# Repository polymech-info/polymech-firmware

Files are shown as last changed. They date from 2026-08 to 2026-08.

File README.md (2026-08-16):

# Polymech FW Apps

Monorepo for the Polymech Cassandra control system — ESP32-S3 firmware, web interface, maintenance tooling, and supporting libraries.

> **WIP / Roadmap**
> - Adopt new widget system for the web interface
> - Migrate firmware build to ESP-IDF native (drop PlatformIO)

## Overview

The firmware is a general-purpose embedded control platform for industrial recycling and forming machinery. **Cassandra** is the reference application built on top of it — not the framework itself. Any application is composed by enabling features in `config.h` and dropping local overrides into `config-user.h`, with no changes required to the core codebase.

**Composable components** (toggled via `#define`):

- **VFDs** — Sako, Delta, HY (RS-485 Modbus RTU)
- **Temperature control** — Omron E5 series PID controllers (up to N devices, configurable slave IDs)
- **Pressure / force** — load cells, press cylinders, solenoids
- **Motion** — stepper axes, joystick, operator switches
- **Profiles** — temperature warm-up sequences, pressure profiles, signal plots
- **Connectivity** — Modbus TCP, RS-485, REST API, WebSocket, LittleFS web UI
- **Budgeting** — amperage budget manager for shared power rails

The web interface (`modbus-ui`) is equally composable: pages and widgets map to the Modbus/REST surface exposed by whatever components are enabled in firmware.

**Supported machine types:** injection moulders, sheet presses, shredders, extruders, vending machines, and any custom application that combines VFDs, PID zones, and relay/solenoid outputs.

> **Status:** Battle-tested over many months of continuous operation on real production hardware.

## Repository Layout

| Path | Description |
|---|---|
| [`cassandra-rc2/`](./cassandra-rc2/README.md) | Main firmware (PlatformIO / ESP32-S3). Exposes Serial, Modbus TCP, and a REST/Web UI. |
| [`web/packages/modbus-ui/`](./web/packages/modbus-ui/) | React operator interface for the device, served over WiFi. |
| [`web/packages/client/`](./web/packages/client/) | Shared TypeScript client library used by the web packages. |
| [`cli-ts/`](./cli-ts/) | Node.js / TypeScript maintenance CLI — configuration management, network setup, signal plotting, and device scripting. |
| [`mb-script/`](./mb-script/) | Scriptable Modbus sequencer firmware for automated register-level testing and commissioning. |
| [`playground/`](./playground/) | Isolated PlatformIO sandbox for prototyping firmware features before merging into the main build. |
| [`tools/`](./tools/) | Pre-built Windows binaries and upload scripts (`esptool`, `espflash`, Modbus Poll/Slave, flash download tool, `zadig`, etc.). |
| [`vendor/`](./vendor/) | Third-party datasheets and reference material (Delta, Omron, Waveshare, HY, Kincony, and others). |

## Requirements

### Firmware (`cassandra-rc2/`)

The firmware supports two build backends. **ESP-IDF native** is the target going forward; PlatformIO remains available for the existing Waveshare/ESP32-S3 targets.

| Requirement | Notes |
|---|---|
| **PlatformIO Core** (`pio`) | `pip install platformio`. Used for `waveshare` / `waveshare-release` / `esp32-p4-evboard` environments. |
| **ESP-IDF v5.3.1** | Install via the [Espressif installer](https://docs.espressif.com/projects/esp-idf/en/stable/esp32s3/get-started/). Path assumed at `C:\Espressif\frameworks\esp-idf-v5.3.1`. Used by `idf:build` / `idf:flash` / `idf:monitor` scripts (via `scripts/idf-*.sh`). |
| **CMake ≥ 3.24** | Bundled with ESP-IDF; ensure it is on `PATH` for native IDF builds. |
| **Python ≥ 3.10** | Required by PlatformIO, `esptool`, Modbus test scripts, and the nanopb generator (`scripts/run_nanopb_generator.py`). Run `npm run idf:setup` to install the IDF Python venv. |
| **Node.js ≥ 20 + npm** | Drives all `npm run …` wrapper scripts. |
| **VSCode** | Recommended editor. Install either: |
| &nbsp;&nbsp;↳ **ms-vscode.cpptools** | Microsoft C/C++ extension — works out of the box with the PlatformIO-generated `compile_commands.json` (`npm run index`). |
| &nbsp;&nbsp;↳ **llvm-vs-code-extensions.vscode-clangd** | clangd — faster indexing; requires the same `compile_commands.json` and disabling ms-cpptools IntelliSense. |
| **Bash** | Required for `idf:*` and `web:*` shell scripts. On Windows use Git Bash or WSL. |

### Web interface (`web/packages/modbus-ui/`)

| Requirement | Notes |
|---|---|
| **Node.js ≥ 20 + npm** | `npm install` in `web/packages/modbus-ui/` and `web/packages/client/`. |

### Maintenance CLI (`cli-ts/`)

| Requirement | Notes |
|---|---|
| **Node.js ≥ 20 + npm** | `npm install` in `cli-ts/`. |

## References

- [OSR - Plastic Legacy Firmware (Shredders, Printhead)](https://git.polymech.info/osr-plastic/osr-firmware.git)
- [Cassandra 65cm — PolyMech Service](https://service.polymech.info/user/3bb4cfbf-318b-44d3-a9d3-35680e738421/pages/cassandra-65cm)
- [Elena - Injection Machine (Motorized) — PolyMech Service](https://service.polymech.info/user/3bb4cfbf-318b-44d3-a9d3-35680e738421/pages/elena-injection-machine-motorized)

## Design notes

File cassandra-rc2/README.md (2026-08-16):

# Polymech Cassandra Firmware

This repository contains the firmware for the Polymech Cassandra project, running on an ESP32-S3.

## Overview

The firmware manages various hardware components and provides multiple interfaces for control and monitoring:

* **Serial Interface:** For debugging, testing, and direct command execution.
* **Modbus TCP Server:** Allows interaction with components using the Modbus protocol over WiFi.
* **REST API & Web UI:** Provides a web-based interface (status page, API documentation) and a RESTful API for interacting with the system over WiFi.

## Architecture

The firmware is built upon a component-based architecture:

* **`App` / `PHApp`:** The main application class (`src/PHApp.h`).
* **`Component`:** Base class (`src/Component.h`) for all functional units.
* **`Bridge`:** (`src/Bridge.h`) Facilitates serial command dispatch.
* **`SerialMessage`:** (`src/SerialMessage.h`) Handles serial communication.
* **`ModbusManager`:** (`src/ModbusManager.h`) Manages the Modbus TCP server.
* **`RESTServer`:** (`src/RestServer.h`) Implements the web server and REST API.
* **Details:** See [docs/components.md](./docs/components.md) for how components are structured, configured, and added.

## Interfaces

### 1. Serial Communication

A command-line interface is available over the USB serial port used for programming and monitoring.

* **Purpose:** Debugging, direct method calls on components.
* **Command Format:** `<<component_id;call_type;flags;payload:arg1:arg2...>>`
* **Examples & Details:** See [docs/serial.md](./docs/serial.md)
* **Sending Commands:** Use `npm run send -- "<command_string>"` or a standard serial terminal.

### 2. Modbus TCP

The device runs a Modbus TCP server (slave/responder) on port 502.

* **Implementation:** Managed by `ModbusManager` using the `eModbus` library.
* **Component Interaction:** Components supporting Modbus (like `Relay` or `PHApp` itself) implement `readNetworkValue` and `writeNetworkValue` methods. They are registered with the `ModbusManager` along with their corresponding Modbus addresses.
* **Configuration:** Modbus addresses are defined in `src/config-modbus.h`.
* **Design Details:** See [docs/design-network.md](./docs/design-network.md)
* **Testing:** Use the `python scripts/modbus_*.py` scripts directly (npm script argument passing has issues):

    ```bash
    # Read Coil 51
    python scripts/modbus_read_coils.py --address 51 --ip-address <DEVICE_IP>
    # Write Coil 51 ON
    python scripts/modbus_write_coil.py --address 51 --value 1 --ip-address <DEVICE_IP>
    # Read Register 20
    python scripts/modbus_read_registers.py --address 20 --ip-address <DEVICE_IP>
    # Write Register 20
    python scripts/modbus_write_register.py --address 20 --value 123 --ip-address <DEVICE_IP>
    ```

### 3. Web Interface & REST API

A web server runs on port 80, providing:

* **Status Page:** `http://<DEVICE_IP>/`
* **Swagger UI:** `http://<DEVICE_IP>/api-docs` (Interactive API documentation)
* **REST API:** `http://<DEVICE_IP>/api/v1/...`
* **Working Endpoints:**
  * `GET /api/v1/system/info`: Device status.
  * `GET /api/v1/coils`: List of registered coils.
  * `GET /api/v1/registers`: List of registered registers.
  * `GET /api/v1/coils?address=<addr>`: Read a specific registered coil.
  * `GET /api/v1/registers?address=<addr>`: Read a specific registered register.
  * `POST /api/v1/relay/test`: Trigger internal relay test.
* **Non-Functional Endpoints (Known Issue):**
  * `POST /coils/{address}`: Returns 404.
  * `POST /registers/{address}`: Returns 404.
* **Details & Examples:** See [docs/web.md](./docs/web.md)
* **Testing:** Use `npm run test-api-ip` (note that some tests related to POST endpoints will fail).

## Building and Development

See [firmware/.cursor/rules](./.cursor/rules) for a summary of common workflow commands.

**Key `npm` Scripts:**

* `npm run build`: Compile the firmware.
* `npm run upload`: Upload the firmware to the device.
* `npm run clean`: Clean build artifacts.
* `npm run monitor`: Open the serial monitor.
* `npm run build-web`: Generate web assets (from `swagger.yaml`, `front/`) and build firmware.
* `npm run send -- "<command>"`: Send a serial command.
* `npm run test-api-ip`: Run the REST API test script against the device IP.
* *(Modbus tests need direct python execution, see Modbus section above)*

## Configuration

* **Hardware Pins, Features:** `src/config.h`, `src/config_adv.h`
* **WiFi Credentials:** `src/config_secrets.h` (ensure this file exists and is populated)
* **Modbus Addresses:** `src/config-modbus.h`
* **Component IDs:** `src/enums.h` (enum `COMPONENT_KEY`)

## Todos

### Web

* [x] pid stats
* [ ] prof enabled
* [ ] warmup toggle
* [-] press prof - remaining ( parent )
* [ ] auto - interlock ( rs 485 connect ) => modes
* [ ] press : sp ( ui - mobile)
* [ ] partitions : settings not applied

### FW

* [x] press - profile ( check abort => vis error )
* [x] sp drag / lag

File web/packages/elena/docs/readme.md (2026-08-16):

# Cassandra RC2 Temperature Control System

The Cassandra RC2 is a temperature control system designed for precise thermal management across multiple heat zones. This web interface allows operators to monitor and control various heating elements arranged in zones with support for temperature profiles.

## System Architecture

The following diagram shows the high-level architecture of the Cassandra RC2 system:

```mermaid
flowchart TD
    UI[Web Interface] --> API[API Client]
    API --> CS[Controller Service]
    API --> PS[Profile Service]
    API --> ZS[Zone Service]
    CS --> SS[Storage Service]
    PS --> SS
    ZS --> SS
    SS --> DB[Supabase Database]
```

## Data Model

The core data entities in the system are:

```mermaid
erDiagram
    HeatZone ||--o{ Controller : contains
    Controller }|--o| TemperatureProfile : runs
    TemperatureProfile ||--|{ ControlPoint : contains

    HeatZone {
        string id
        string name
        string description
    }

    Controller {
        string id
        string name
        number currentTemp
        number targetTemp
        number minTemp
        number maxTemp
        number slaveId
        number updateInterval
        string currentProfile
        boolean isRunning
        string lastUpdated
        string zoneId
    }

    TemperatureProfile {
        string id
        string name
        string description
        array controlPoints
        number duration
        string createdAt
        string updatedAt
    }

    ControlPoint {
        number x
        number y
        number handleX
        number handleY
        string type
    }
```

## Component Hierarchy

The React component hierarchy for the main interface:

```mermaid
flowchart TD
    Index[Index Page] --> MainNav[Main Navigation]
    Index --> ZoneCard[Zone Cards]
    ZoneCard --> ZMC[Zone Master Control]
    ZoneCard --> TC[Temperature Controllers]
    Index --> Dialogs[Dialog Components]
    Dialogs --> PD[Profile Dialog]
    Dialogs --> ACD[Add Controller Dialog]
    Dialogs --> ECD[Edit Controller Dialog]
    Dialogs --> AZD[Add Zone Dialog]

    TC --> Info[Controller Info]
    TC --> TempDisplay[Temperature Display]
    TC --> Controls[Control Buttons]

    ZMC --> Visualization[Heat Press Visualization]
    ZMC --> ZoneControls[Zone-wide Controls]
    ZMC --> ProfileProgress[Profile Progress]
```

## API Structure

The API client provides these main function groups:

```mermaid
flowchart LR
    API[API Client] --> ZoneFunctions[Zone Functions]
    API --> ProfileFunctions[Profile Functions]
    API --> ControllerFunctions[Controller Functions]

    ZoneFunctions --> getZones[getZones]
    ZoneFunctions --> getZone[getZone]
    ZoneFunctions --> createZone[createZone]
    ZoneFunctions --> deleteZone[deleteZone]
    
    ProfileFunctions --> getProfiles[getProfiles]
    ProfileFunctions --> getProfile[getProfile]
    ProfileFunctions --> createProfile[createProfile]
    ProfileFunctions --> updateProfile[updateProfile]
    ProfileFunctions --> deleteProfile[deleteProfile]
    
    ControllerFunctions --> getControllers[getControllers]
    ControllerFunctions --> getController[getController]
    ControllerFunctions --> updateController[updateController]
    ControllerFunctions --> startController[startController]
    ControllerFunctions --> stopController[stopController]
    ControllerFunctions --> createController[createController]
    ControllerFunctions --> deleteController[deleteController]
```

## Temperature Control Flow

The temperature control system functions as follows:

```mermaid
sequenceDiagram
    actor User
    participant UI as Web Interface
    participant API as API Client
    participant Storage as Storage Service
    
    User->>UI: Set target temperature
    UI->>API: updateController(id, {targetTemp})
    API->>Storage: Save updated controller
    Storage-->>API: Confirmation
    API-->>UI: Updated controller object
    UI-->>User: Display updated temperature
    
    User->>UI: Apply temperature profile
    UI->>API: startController(id, profileId)
    API->>Storage: Update controller with profile
    Storage-->>API: Confirmation
    API-->>UI: Updated controller with profile
    UI-->>User: Display profile progress
    
    loop While profile is running
        UI->>UI: Calculate temperature based on profile
        UI->>UI: Update controller display
    end
```

## Zone Management

Heat zones organize controllers into logical groups:

```mermaid
flowchart TD
    Zone1[Zone: Top Platen] --> TC1[Controller 1: Top-Front]
    Zone1 --> TC2[Controller 2: Top-Back]
    Zone2[Zone: Bottom Platen] --> TC3[Controller 3: Bottom-Front]
    Zone2 --> TC4[Controller 4: Bottom-Back]

    subgraph MasterControl[Zone Master Controls]
        SetAll[Set All Temperatures]
        ApplyProfile[Apply Profile to Zone]
        StopAll[Stop All Controllers]
    end

    Zone1 --- MasterControl
    Zone2 --- MasterControl
```

## Temperature Profiles

Temperature profiles define heating patterns over time:

```mermaid
graph LR
    Profile[Temperature Profile] --> Points[Control Points]
    Points --> Bezier[Bezier Curve Calculator]
    Bezier --> Temp[Temperature at Time t]
    
    subgraph Timeline
        Start[Start] --> CP1[Control Point 1]
        CP1 --> CP2[Control Point 2]
        CP2 --> CP3[Control Point 3]
        CP3 --> End[End]
    end
```

## User Interface Workflow

```mermaid
stateDiagram
    [*] --> Dashboard
    Dashboard --> ViewZones
    Dashboard --> AddZone
    
    ViewZones --> ManageControllers
    ViewZones --> ZoneMasterControl
    
    AddZone --> Dashboard
    
    ManageControllers --> AddController
    ManageControllers --> EditController
    ManageControllers --> DeleteController
    ManageControllers --> StartController
    ManageControllers --> StopController
    
    StartController --> SelectProfile
    SelectProfile --> ProfileRunning
    
    ProfileRunning --> StopController
    StopController --> ManageControllers
    
    AddController --> ManageControllers
    EditController --> ManageControllers
    DeleteController --> ManageControllers
    
    ZoneMasterControl --> SetAllTemperatures
    ZoneMasterControl --> ApplyProfileToAll
    ZoneMasterControl --> StopAllControllers
    
    SetAllTemperatures --> ViewZones
    ApplyProfileToAll --> ViewZones
    StopAllControllers --> ViewZones
```

## Getting Started

To run the Cassandra RC2 web interface:

1. Install dependencies:
   ```
   npm install
   ```

2. Start the development server:
   ```
   npm run dev
   ```

3. Access the web interface at http://localhost:5173

## Technologies Used

- React with TypeScript
- TanStack Query for data fetching and caching
- Shadcn UI components
- Supabase for data storage
- Bezier curve calculations for temperature profiles

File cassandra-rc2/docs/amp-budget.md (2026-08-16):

# Amperage Budget Manager Design

## 1. Introduction

This document outlines the design for the `AmperageBudgetManager` component. This component is responsible for managing a group of `OmronE5` temperature controllers (representing heating partitions) to ensure their total power consumption does not exceed a predefined budget. It achieves this by serializing the activation (`run()`) of the controllers based on heating demand (PV < SP) and available budget, using a fair scheduling algorithm.

## 2. Goals

*   Limit the instantaneous total power consumption of a group of `OmronE5` devices.
*   Provide a configurable power budget (in Watts).
*   Implement a fair scheduling mechanism (round-robin with preemption) to ensure all partitions needing heat get a chance to run over time.
*   Integrate seamlessly with the existing `PHApp` and `OmronE5` components.
*   Control `OmronE5` devices using their existing `run()` and `stop()` methods.

## 3. Component Architecture

### 3.1 Class Diagram

```mermaid
classDiagram
    Component <|-- AmperageBudgetManager
    AmperageBudgetManager o-- "0..*" ManagedDevice : contains
    ManagedDevice o-- OmronE5 : references
    PHApp o-- AmperageBudgetManager : owns
    PHApp o-- "*" OmronE5 : owns

    class Component {
        +setup() virtual
        +loop() virtual
        +info() virtual
    }

    class OmronE5 {
        +run() bool
        +stop() bool
        +getPV(uint16_t&) bool
        +getSP(uint16_t&) bool
        +isRunning() bool
        +getConsumption() uint32_t
        -_consumption : uint32_t
    }

    class ManagedDevice {
      +OmronE5* device
      +ManagedState state
      +uint8_t originalIndex
    }

    class AmperageBudgetManager {
        +AmperageBudgetManager(uint32_t wattBudget)
        +addManagedDevice(OmronE5* device)
        +setup() override
        +loop() override
        +info() override
        -uint32_t _wattBudget
        -ManagedDevice _managedDevices[]
        -uint8_t _numDevices
        -uint8_t _maxDevices
        -uint8_t _nextDeviceIndex
        -ManagedState state // Enum definition reference
        -_allocateBudget()
    }

    class PHApp {
        +setup()
        +loop()
    }

    enum ManagedState {
      UNKNOWN
      IDLE
      REQUESTING_HEAT
      HEATING
    }

    AmperageBudgetManager ..> ManagedState : uses
    ManagedDevice ..> ManagedState : uses
```

### 3.2 Data Structures

*   **`_wattBudget`**: `uint32_t` - The maximum combined wattage allowed for managed devices in the `HEATING` state.
*   **`_managedDevices`**: An array or similar structure holding pointers to the managed `OmronE5` instances along with their current state (`ManagedState`) and original registration order for stable sorting.
*   **`_nextDeviceIndex`**: `uint8_t` - Index used for the round-robin starting point.
*   **`ManagedState`**: Enum (`UNKNOWN`, `IDLE`, `REQUESTING_HEAT`, `HEATING`) - Tracks the state of each managed device from the budget manager's perspective.

### 3.3 Key Methods

*   **`AmperageBudgetManager(uint32_t wattBudget)`**: Constructor, sets the budget.
*   **`addManagedDevice(OmronE5* device)`**: Registers an `OmronE5` instance to be managed.
*   **`setup()`**: Initializes the manager, sets initial states.
*   **`loop()`**: The core logic, executed repeatedly. Checks device status, calculates needs, allocates budget, and sends `run()`/`stop()` commands.
*   **`info()`**: Prints debugging information about managed devices and budget status.
*   **`_allocateBudget()`**: Internal helper encapsulating the budget allocation logic described in section 4.

## 4. Scheduling Logic (Round-Robin with Preemption)

The `loop()` method executes the following logic periodically:

1.  **Identify Needs & Stop Unneeded:**
    *   Iterate through all `_managedDevices`.
    *   For each device, get its current PV, SP, and `isRunning()` status.
    *   If `PV >= SP` (wants to stop) and its state is `HEATING` or `REQUESTING_HEAT`:
        *   Call `device->stop()`.
        *   Set its state to `IDLE`.
    *   If `PV < SP` (wants to run):
        *   If its state is `IDLE`, change state to `REQUESTING_HEAT`.
    *   Keep track of devices currently in `HEATING` state and those in `REQUESTING_HEAT`.

2.  **Prioritize and Allocate Budget (`_allocateBudget`):**
    *   Create a list `potentialRunners` containing all devices currently in the `REQUESTING_HEAT` or `HEATING` state.
    *   Sort `potentialRunners` based on their original registration order, but starting the comparison cycle from `_nextDeviceIndex` to implement round-robin priority. (Effectively, devices closer to `_nextDeviceIndex` in the circular list get higher priority for this cycle).
    *   Initialize `currentWattage = 0`.
    *   Create an empty list `willRun`.
    *   Iterate through the prioritized `potentialRunners`:
        *   Get the device's consumption: `device->getConsumption()`.
        *   If `currentWattage + device->getConsumption() <= _wattBudget`:
            *   Add the device to the `willRun` list.
            *   `currentWattage += device->getConsumption()`.

3.  **Apply Changes:**
    *   Iterate through all `_managedDevices` again:
        *   If the device is in the `willRun` list:
            *   If its state was `REQUESTING_HEAT`, call `device->run()`.
            *   Set its state to `HEATING`.
        *   Else (device is *not* in `willRun` list):
            *   If its state was `HEATING`, call `device->stop()`.
            *   Set its state to `REQUESTING_HEAT` (if PV < SP) or `IDLE` (if PV >= SP - handled in step 1).

4.  **Update Robin Index:**
    *   Increment `_nextDeviceIndex` (wrapping around) to ensure the priority shifts in the next cycle: `_nextDeviceIndex = (_nextDeviceIndex + 1) % _numDevices`.

### 4.1 State Diagram (for a single managed OmronE5)

```mermaid
stateDiagram-v2
    [*] --> IDLE : Initialized / PV >= SP

    IDLE --> REQUESTING_HEAT : PV < SP detected
    IDLE --> IDLE : PV >= SP

    REQUESTING_HEAT --> HEATING : Budget allocated & run() called
    REQUESTING_HEAT --> IDLE : PV >= SP detected & stop() called
    REQUESTING_HEAT --> REQUESTING_HEAT : Budget not available

    HEATING --> IDLE : PV >= SP detected & stop() called
    HEATING --> REQUESTING_HEAT : Budget revoked & stop() called
    HEATING --> HEATING : Budget remains allocated & PV < SP
```

### 4.2 Sequence Diagram (Simplified `loop` cycle)

```mermaid
sequenceDiagram
    participant L as loop()
    participant BM as AmperageBudgetManager
    participant O1 as OmronE5_1
    participant O2 as OmronE5_2
    participant O3 as OmronE5_3

    loop over Managed Devices
        L->>O1: getPV(), getSP(), isRunning()
        L->>BM: Update O1 State (e.g., IDLE to REQUESTING_HEAT)
        L->>O2: getPV(), getSP(), isRunning()
        L->>BM: Update O2 State (e.g., HEATING to IDLE)
        L->>O2: stop()
        L->>O3: getPV(), getSP(), isRunning()
        L->>BM: Update O3 State (e.g., HEATING remains HEATING)
    end

    L->>BM: _allocateBudget()
    BM->>O1: getConsumption()
    BM->>O3: getConsumption()
    BM-->>L: Return willRun = [O1, O3]

    loop over Managed Devices
        L->>BM: Check if O1 in willRun -> Yes
        BM->>O1: run() (if state was REQUESTING_HEAT)
        BM->>BM: Set O1 state = HEATING

        L->>BM: Check if O2 in willRun -> No
        BM->>BM: Set O2 state = IDLE (already stopped)

        L->>BM: Check if O3 in willRun -> Yes
        BM->>BM: Set O3 state = HEATING (no change needed)
    end

    L->>BM: Increment _nextDeviceIndex
```

## 5. Configuration and Integration

*   **Instantiation:** An instance of `AmperageBudgetManager` should be created in `PHApp`.
    ```cpp
    // In PHApp.h (example)
    #include "components/AmperageBudgetManager.h"
    // ...
    AmperageBudgetManager* budgetManager;

    // In PHApp::setup() (example)
    _amperageBudget = new AmperageBudgetManager(10000); // Example: 10kW budget
    _amperageBudget->addManagedDevice(_omron1); // Assuming _omron1 is an OmronE5*
    _amperageBudget->addManagedDevice(_omron2);
    // ... add other Omrons
    _amperageBudget->setup();
    ```
*   **Budget Value:** The power budget (Watts) is passed to the constructor. This could be made configurable via Modbus or REST API by adding setter methods and potentially exposing them through `PHApp`.
*   **Device Consumption:** The manager relies on `OmronE5::getConsumption()`. This method needs to be added to the `OmronE5` class, returning the `_consumption` value (which might also need to be made configurable per `OmronE5` instance).
*   **PHApp Loop:** `AmperageBudgetManager::loop()` must be called from `PHApp::loop()`.
    ```cpp
    // In PHApp::loop()
    if (_amperageBudget) {
        _amperageBudget->loop();
    }
    ```

## 6. Potential Issues and Refinements

*   **SP Reachability:** If the budget is too low relative to the heat loss and the number/power of partitions, the system might struggle or fail to reach the Set Point (SP) on all devices. This requires careful tuning of the budget.
*   **Rapid Cycling:** If the budget forces frequent starting/stopping, it might cause wear on relays (if used by the Omron output). Hysteresis could be added (e.g., require PV to be `SP + delta` before stopping, or `SP - delta` before wanting heat).
*   **Consumption Accuracy:** The accuracy depends on the configured `_consumption` value in each `OmronE5`. If actual consumption varies significantly, the budget management might be inaccurate.
*   **Error Handling:** The design assumes `OmronE5` methods succeed. Robust error handling (checking return values of `run()`, `stop()`, `getPV`, etc.) should be added.
*   **Dynamic Budget:** The budget could be adjusted dynamically based on external factors (e.g., total system load).
*   **Advanced Scheduling:** More complex scheduling (e.g., prioritizing devices further from SP) could be implemented if simple round-robin proves insufficient.

## 7. Mathematical Modeling and Optimization Considerations

This section explores the mathematical underpinnings and potential optimizations for the budget management system.

### 7.1 Core Budget Constraint

Let N be the number of managed `OmronE5` devices. Let P_i be the power consumption (Watts) of device i when heating, obtained via `device[i]->getConsumption()`. Let S_i(t) be the state of device i at time t, where S_i(t) = 1 if the device is actively heating (state `HEATING`) and S_i(t) = 0 otherwise (`IDLE`, `REQUESTING_HEAT`, or stopped by the manager).

The fundamental constraint enforced by the `AmperageBudgetManager` at any given time t is:

```
Sum(S_i(t) * P_i for i=1 to N) <= W_budget
```

where W_budget is the configured maximum power budget.

The scheduling algorithm (Section 4, Step 2) effectively selects the subset of devices H(t) = { i | S_i(t) = 1 } such that this inequality holds, prioritizing devices based on need (PV_i < SP_i) and the round-robin index.

### 7.2 Error Sources

Potential sources of error can affect the system's ability to precisely meet the budget or achieve optimal heating:

1.  **Consumption Estimation Error (epsilon_P):** The actual power P_i_actual drawn by a heater might differ from the configured P_i. The total actual power is `Sum(P_i_actual for i in H(t))`. The budget calculation error is `Sum(P_i - P_i_actual for i in H(t))`. 
    *   *Mitigation:* Calibration, using more accurate power measurement if available, adding a safety margin to W_budget.
2.  **Measurement Delay (tau_m):** Time lag between a temperature change, its measurement by the `OmronE5` (PV update), and the `AmperageBudgetManager` reading it.
3.  **Control Delay (tau_c):** Time lag between the manager deciding to change a device's state (`run()`/`stop()`) and the command being executed and having an effect (e.g., RS485 communication delay, relay actuation time).
4.  **Sampling Rate:** The `loop()` frequency of the `AmperageBudgetManager` determines how quickly changes are detected and acted upon. A slower rate increases the effective delay.

### 7.3 Thermal Inertia and Dynamics

Each heating partition i has thermal characteristics. A simplified model might be a first-order system:

```
C_i * d(PV_i)/dt = Q_heat_i(t) - Q_loss_i(t)
```

where:
*   C_i is the thermal capacitance of partition i.
*   PV_i is the process variable (temperature) of partition i.
*   Q_heat_i(t) is the heat input rate. Q_heat_i(t) = P_i if S_i(t) = 1, and 0 otherwise (assuming idealized heater).
*   Q_loss_i(t) is the heat loss rate, often modeled as `U_i * (PV_i(t) - T_ambient)`, where U_i is a heat transfer coefficient and T_ambient is the ambient temperature.

**Implications:**

*   **Lag:** Due to C_i, the temperature PV_i changes gradually in response to Q_heat_i(t). Stopping heat doesn't instantly stop the temperature rise, potentially leading to overshoot, especially if the Omron's internal PID isn't tuned for intermittent operation.
*   **Interdependence:** Heat loss Q_loss_i(t) might depend not only on T_ambient but also on the temperatures of adjacent partitions (PV_j), creating thermal coupling.
*   **SP Reachability:** If the average heat input allowed by the budget over time (Avg_Q_heat_i) is less than the heat loss at the setpoint (Q_loss_i(SP_i)), the partition may never reach SP_i.
    ```
    Avg_Q_heat_i = P_i * (Average Duty Cycle for i) < Q_loss_i(SP_i)
    ```
*   **Minimum Effective On-Time (tau_min_on_i):** Due to thermal capacitance (C_i) and initial heat loss rate (Q_loss_i(t)), there might be a minimum duration tau_min_on_i for which a heater i must be active (S_i(t) = 1) to produce a significant or useful increase in PV_i. Activating a heater for durations less than tau_min_on_i could be inefficient, consuming power without meaningfully contributing to reaching the setpoint. The scheduling algorithm should ideally ensure that when a device is granted budget, it runs for at least this duration, or consider this constraint when deciding which devices to activate.

### 7.4 Optimization Objectives

Beyond simply staying within budget, optimization could target:

1.  **Minimize Time-to-Setpoint:** Reduce the total time for all devices requesting heat to reach their respective SP_i.
2.  **Maximize Fairness:** Ensure all devices requesting heat receive a proportional amount of heating time over a longer window, preventing starvation.
3.  **Minimize Overshoot:** Reduce the amount PV_i exceeds SP_i after heating stops.
4.  **Minimize Control Effort:** Reduce the frequency of `run()`/`stop()` commands to minimize wear on physical components (like relays).
5.  **Maximize Weighted Priority:** Allow certain devices to have higher priority in budget allocation.

### 7.5 Potential Control Improvements

1.  **Hysteresis:** Introduce a deadband around SP. Only request heat if `PV_i < SP_i - delta_lower` and only stop requesting heat if `PV_i > SP_i + delta_upper`. This reduces rapid cycling near the setpoint.
2.  **Priority Scheduling:** Instead of pure round-robin, prioritize devices based on:
    *   Error magnitude: `SP_i - PV_i`
    *   Time since last heated
    *   Configured static priority
3.  **Predictive Control:** Model the thermal dynamics (C_i, U_i) and predict future PV_i to make more informed decisions about when to start/stop heating, potentially anticipating overshoot or allocating budget more effectively.
4.  **Duty Cycle Modulation:** If the heating elements support it (unlikely with simple `run`/`stop`), modulate the *power* P_i rather than just on/off state, allowing finer budget control.
5.  **Adaptive Budget:** Adjust W_budget based on overall system state or external inputs.

## 8. Required Changes to OmronE5

*   Add a public method `uint32_t getConsumption() const;` to `OmronE5.h`.
*   Implement `OmronE5::getConsumption()` in `OmronE5.cpp` to return the value of the `_consumption` member variable.

```cpp
// In OmronE5.h
public:
    // ... other methods ...
    uint32_t getConsumption() const; // Add this

// In OmronE5.cpp
uint32_t OmronE5::getConsumption() const {
    return _consumption; // Assuming _consumption holds Watts
}
```

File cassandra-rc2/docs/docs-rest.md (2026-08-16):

# REST API Documentation

This document provides an overview of the RESTful API and WebSocket interface for interacting with the device.

## Authentication

The API does not currently require authentication.

## Base URL

All API endpoints are relative to the device's IP address. For example, if the device IP is `192.168.1.100`, the full URL for `/api/v1/system/info` would be `http://192.168.1.100/api/v1/system/info`.

---

## REST API Endpoints

### System Endpoints

#### Get System Information

- **Endpoint:** `GET /api/v1/system/info`
- **Description:** Retrieves general system information like firmware version, uptime, and memory usage.
- **Response:**
  ```json
  {
    "version": "3ce112f",
    "board": "esp32dev",
    "uptime": 12345,
    "timestamp": 12345678,
    "freeHeapKb": 150.5,
    "maxFreeBlockKb": 100.2,
    "cpuTicks": 123456789,
    "loopDurationMs": 500,
    "cpuLoadPercent": null
  }
  ```
- **cURL Example:**
  ```bash
  curl http://<DEVICE_IP>/api/v1/system/info
  ```
- **Node.js Example:**
  ```javascript
  const fetch = require('node-fetch');

  async function getSystemInfo() {
    try {
      const response = await fetch('http://<DEVICE_IP>/api/v1/system/info');
      const data = await response.json();
      console.log(data);
    } catch (error) {
      console.error('Error fetching system info:', error);
    }
  }

  getSystemInfo();
  ```

#### Get System Logs

- **Endpoint:** `GET /api/v1/system/logs`
- **Description:** Retrieves the system logs.
- **Query Parameters:**
  - `level` (optional): The minimum log level to retrieve. Can be one of `none`, `error`, `warning`, `notice`, `trace`, `verbose`. Defaults to `verbose`.
- **Response:** An array of log strings.
  ```json
  [
    "I: System initialized.",
    "W: Network connection weak."
  ]
  ```
- **cURL Example:**
  ```bash
  curl http://<DEVICE_IP>/api/v1/system/logs?level=warning
  ```
- **Node.js Example:**
  ```javascript
  const fetch = require('node-fetch');

  async function getLogs() {
    try {
      const response = await fetch('http://<DEVICE_IP>/api/v1/system/logs?level=warning');
      const data = await response.json();
      console.log(data);
    } catch (error) {
      console.error('Error fetching logs:', error);
    }
  }

  getLogs();
  ```

#### Get/Set Log Level

- **Endpoint:**
  - `GET /api/v1/system/log-level`
  - `GET /api/v1/system/log-level?level=<level>`
- **Description:**
  - `GET` without parameters retrieves the current log level.
  - `GET` with the `level` parameter sets a new log level.
- **Query Parameters:**
  - `level` (for setting): The new log level. One of `none`, `error`, `info`, `warning`, `notice`, `trace`, `verbose`.
- **Response (Get):**
  ```json
  {
    "success": true,
    "level": "verbose"
  }
  ```
- **Response (Set):**
  ```json
  {
    "success": true,
    "level": "warning"
  }
  ```
- **cURL Example (Get):**
  ```bash
  curl http://<DEVICE_IP>/api/v1/system/log-level
  ```
- **cURL Example (Set):**
  ```bash
  curl http://<DEVICE_IP>/api/v1/system/log-level?level=warning
  ```
- **Node.js Example (Set):**
  ```javascript
  const fetch = require('node-fetch');

  async function setLogLevel(level) {
    try {
      const response = await fetch(`http://<DEVICE_IP>/api/v1/system/log-level?level=${level}`);
      const data = await response.json();
      console.log(data);
    } catch (error) {
      console.error('Error setting log level:', error);
    }
  }

  setLogLevel('warning');
  ```

#### List Filesystem

- **Endpoint:** `GET /api/v1/fs/list`
- **Description:** Lists files and directories in the root of the device's filesystem (LittleFS).
- **Response:**
  ```json
  [
    {
      "name": "/index.html",
      "type": "file",
      "size": 1234
    },
    {
      "name": "/config",
      "type": "directory",
      "size": 0
    }
  ]
  ```
- **cURL Example:**
  ```bash
  curl http://<DEVICE_IP>/api/v1/fs/list
  ```

### Modbus Endpoints

These endpoints provide access to Modbus data (coils and registers).

#### Get All Coils

- **Endpoint:** `GET /api/v1/coils`
- **Description:** Retrieves the state of all mapped coils.
- **Response:**
  ```json
  {
    "coils": [
      {
        "address": 1,
        "value": 1,
        "name": "Motor_On",
        "component": "Motor",
        "id": 101,
        "type": 1,
        "flags": 0,
        "group": "Motors"
      }
    ]
  }
  ```
- **cURL Example:**
  ```bash
  curl http://<DEVICE_IP>/api/v1/coils
  ```

#### Get Single Coil

- **Endpoint:** `GET /api/v1/coils?address=<address>`
- **Description:** Retrieves the state of a single coil by its address.
- **Query Parameters:**
  - `address`: The address of the coil.
- **Response:**
  ```json
  {
    "address": 1,
    "value": true
  }
  ```
- **cURL Example:**
  ```bash
  curl http://<DEVICE_IP>/api/v1/coils?address=1
  ```

#### Set Single Coil

- **Endpoint:** `POST /api/v1/coils/<address>?value=<value>`
- **Description:** Sets the state of a single coil.
- **URL Parameters:**
  - `address`: The address of the coil.
- **Query Parameters:**
  - `value`: The new state of the coil (`1`/`true` or `0`/`false`).
- **Response:**
  ```json
  {
    "success": true,
    "address": 51,
    "value": true
  }
  ```
- **cURL Example:**
  ```bash
  curl -X POST "http://<DEVICE_IP>/api/v1/coils/51?value=true"
  ```
- **Node.js Example:**
  ```javascript
  const fetch = require('node-fetch');

  async function setCoil(address, value) {
    try {
      const response = await fetch(`http://<DEVICE_IP>/api/v1/coils/${address}?value=${value}`, {
        method: 'POST'
      });
      const data = await response.json();
      console.log(data);
    } catch (error) {
      console.error(`Error setting coil ${address}:`, error);
    }
  }

  setCoil(51, true);
  ```

#### Get All Registers

- **Endpoint:** `GET /api/v1/registers`
- **Description:** Retrieves the value of all mapped registers.
- **Query Parameters (optional):**
  - `page`: The page number to retrieve (0-indexed). Defaults to 0.
  - `pageSize`: The number of registers per page. Defaults to 20.
- **Response (with pagination):**
  ```json
  {
    "registers": [
      {
        "error": 0,
        "address": 100,
        "value": 1234,
        "name": "Temperature_Setpoint",
        "component": "Heater",
        "id": 201,
        "type": 3,
        "slaveId": 1,
        "flags": 0,
        "group": "Heating"
      }
    ],
    "meta": {
      "page": 0,
      "pageSize": 20,
      "totalRegisters": 256,
      "totalPages": 13
    }
  }
  ```
- **cURL Example (with pagination):**
  ```bash
  curl http://<DEVICE_IP>/api/v1/registers?page=1&pageSize=50
  ```
  ```bash
  curl http://<DEVICE_IP>/api/v1/registers
  ```

#### Get Single Register

- **Endpoint:** `GET /api/v1/registers?address=<address>`
- **Description:** Retrieves the value of a single register by its address.
- **Query Parameters:**
  - `address`: The address of the register.
- **Response:**
  ```json
  {
    "address": 100,
    "value": 1234
  }
  ```
- **cURL Example:**
  ```bash
  curl http://<DEVICE_IP>/api/v1/registers?address=100
  ```

#### Set Single Register

- **Endpoint:** `POST /api/v1/registers/<address>?value=<value>`
- **Description:** Sets the value of a single holding register.
- **URL Parameters:**
  - `address`: The address of the register.
- **Query Parameters:**
  - `value`: The new integer value for the register (16-bit signed).
- **Response:**
  ```json
  {
    "success": true,
    "address": 20,
    "value": 42
  }
  ```
- **cURL Example:**
  ```bash
  curl -X POST "http://<DEVICE_IP>/api/v1/registers/20?value=42"
  ```
- **Node.js Example:**
  ```javascript
  const fetch = require('node-fetch');

  async function setRegister(address, value) {
    try {
      const response = await fetch(`http://<DEVICE_IP>/api/v1/registers/${address}?value=${value}`, {
        method: 'POST'
      });
      const data = await response.json();
      console.log(data);
    } catch (error) {
      console.error(`Error setting register ${address}:`, error);
    }
  }

  setRegister(20, 42);
  ```

#### Get Modbus Address Mappings

- **Endpoint:** `GET /api/v1/mappings`
- **Description:** Retrieves the list of all Modbus address mappings.
- **cURL Example:**
  ```bash
  curl http://<DEVICE_IP>/api/v1/mappings
  ```

---

## WebSocket API

For real-time data streaming and more complex interactions, a WebSocket interface is provided.

- **Endpoint:** `ws://<DEVICE_IP>/ws`

### Connection

A client can connect to the WebSocket endpoint to receive real-time updates and send commands.

**Node.js Example:**
```javascript
const WebSocket = require('ws');

const ws = new WebSocket('ws://<DEVICE_IP>/ws');

ws.on('open', function open() {
  console.log('Connected to WebSocket');
  // Send a command to get system info
  ws.send(JSON.stringify({ command: 'get_sysinfo' }));
});

ws.on('message', function incoming(data) {
  console.log('Received:', JSON.parse(data));
});

ws.on('close', function close() {
  console.log('Disconnected from WebSocket');
});

ws.on('error', function error(err) {
  console.error('WebSocket error:', err);
});
```

### Commands

Commands are sent as JSON strings.

- `get_sysinfo`: Get system information.
- `get_logs`: Get log history.
- `get_coils`: Get all coil values.
- `get_registers`: Get all register values. Supports paging.
- `write_register`: Write to a register. Payload: `{ "command": "write_register", "address": 100, "value": 1234 }`
- `write_coil`: Write to a coil. Payload: `{ "command": "write_coil", "address": 50, "value": true }`

### Register Paging via WebSocket

When requesting all registers via the `get_registers` command, the response can be paginated to handle a large number of registers efficiently.

**Request Payload:**
```json
{
  "command": "get_registers",
  "page": 0,
  "pageSize": 50
}
```

- `page` (optional): The page number to retrieve (0-indexed). Defaults to 0.
- `pageSize` (optional): The number of registers per page. Defaults to 20.

**Response Payload:**

The response is a JSON object containing the data for the requested page and metadata about the pagination.

```json
{
  "type": "registers",
  "data": [
    {
      "error": 0,
      "address": 100,
      "value": 1234,
      "name": "Register_100",
      "component": "CompA",
      "id": 1,
      "type": 3,
      "slaveId": 1,
      "flags": 1,
      "group": "Group1"
    }
    // ... up to pageSize registers
  ],
  "meta": {
    "page": 0,
    "pageSize": 50,
    "totalRegisters": 256,
    "totalPages": 6
  }
}
```

- `type`: The type of the message (`registers`).
- `data`: An array of register objects for the current page.
- `meta`: An object containing pagination details:
  - `page`: The current page number.
  - `pageSize`: The number of items per page.
  - `totalRegisters`: The total number of registers available.
  - `totalPages`: The total number of pages.

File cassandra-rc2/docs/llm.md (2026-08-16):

# LLM Development Workflow Commands

This document outlines the common `npm` commands used during development and testing of the Cassandra firmware, categorized by their function.

## Application Architecture and Adding New Components

The firmware application is primarily managed by the `PHApp` class ([`src/PHApp.h`](../src/PHApp.h), [`src/PHApp.cpp`](../src/PHApp.cpp)). It acts as the central coordinator for various hardware interactions and communication protocols.

**Key Concepts:**

*   **`PHApp`**: The main application class inheriting from `App`. It initializes and manages all other functional units (Components).
*   **`Component`**: A base class ([`src/Component.h`](../src/Component.h)) for modular hardware abstractions (e.g., relays, sensors, potentiometers). Each specific component type (like `Relay`, `POT`) inherits from `Component`.
*   **`ModbusManager`**: Handles Modbus communication ([`src/ModbusManager.h`](../src/ModbusManager.h)). `PHApp` creates and owns the `ModbusManager` instance.
*   **Component Registration**: Components that need to expose data via Modbus are registered with the `ModbusManager` instance within `PHApp`. This typically happens in `PHApp::setup()` or `PHApp::setupModbus()`.
*   **Network Values**: Components implement `readNetworkValue(address)` and `writeNetworkValue(address, value)` methods. The `ModbusManager` calls these methods when Modbus requests target the addresses registered for that component.

**Steps to Add a New Component:**

1.  **Define Modbus Addresses:** Add necessary Modbus register/coil addresses for your new component in [`src/config-modbus.h`](../src/config-modbus.h).
2.  **Create Component Class:**
    *   Create new header (`.h`) and source (`.cpp`) files for your component (e.g., [`src/MyNewSensor.h`](../src/MyNewSensor.h), [`src/MyNewSensor.cpp`](../src/MyNewSensor.cpp)).
    *   In the header, define a class that inherits from `Component`.
    *   Include necessary headers (e.g., `Component.h`).
    *   Declare constructor, `setup()`, `loop()`, `readNetworkValue()`, `writeNetworkValue()`, and any other required methods.
3.  **Implement Component Logic:**
    *   In the source file (`.cpp`), implement the methods declared in the header.
    *   `setup()`: Initialize hardware, pins, etc.
    *   `loop()`: Read sensor values, update internal state, etc.
    *   `readNetworkValue()`: Return the component's state based on the requested Modbus `address`.
    *   `writeNetworkValue()`: Update the component's state based on the requested Modbus `address` and `value`. Return `E_OK` on success or an error code (from [`enums.h`](../src/enums.h)) on failure.
4.  **Integrate into `PHApp`:**
    *   In `PHApp.h`, include the header for your new component.
    *   In `PHApp.h`, declare a pointer to your new component class as a member variable (e.g., `MyNewSensor* mySensor;`).
    *   In `PHApp::setup()`:
        *   Instantiate your component (e.g., `mySensor = new MyNewSensor(/* constructor args */);`).
        *   Call your component's `setup()` method (e.g., `mySensor->setup();`).
        *   If the component uses Modbus, register it with the `ModbusManager`: `modbusManager->registerComponent(mySensor, MY_SENSOR_START_ADDRESS, MY_SENSOR_REGISTER_COUNT);` (using addresses from `config-modbus.h`).
5.  **Cleanup:** In the `PHApp` destructor (`~PHApp()`), delete the component instance (`delete mySensor;`).
6.  **Build:** Add your new `.cpp` file to the build system if necessary (PlatformIO typically picks up source files in `src` automatically). Run `npm run build` to compile.

## Key Packages and Libraries

This project relies on several key software packages and libraries:

*   **PlatformIO**: The core build system and development ecosystem used to manage the toolchain, libraries, building, and uploading for the ESP32.
*   **Arduino Framework (for ESP32)**: Provides a simplified C++ API for interacting with the ESP32 hardware (GPIO, Serial, WiFi, etc.). It runs on top of ESP-IDF.
*   **ESP-IDF (Espressif IoT Development Framework)**: The official low-level development framework from Espressif, providing the drivers and core system functionalities.
*   **npm**: Used as a task runner to execute build, test, and utility scripts defined in `package.json`.
*   **Python**: Used for various helper scripts (located in the `scripts/` directory) for testing, sending commands, and interacting with the device over serial, Modbus, or HTTP.
*   **C++ Libraries (managed by PlatformIO):**
    *   **`ArduinoJson`**: For efficient JSON serialization and deserialization, used heavily in the REST API.
    *   **`ESPAsyncWebServer` / `AsyncTCP`**: Libraries providing asynchronous handling of HTTP requests and TCP connections, forming the basis of the REST API and WebSocket communication.
    *   **`eModbus`**: Handles Modbus RTU/TCP client and server communication.
    *   **`ArduinoLog`**: Provides flexible logging capabilities, including log levels and output redirection (used here for both Serial and the internal log buffer).
    *   **`LittleFS`**: A lightweight filesystem used to store web assets (HTML, CSS, etc.) on the ESP32's flash memory.
    *   **`WiFi` / `ESPmDNS`**: Standard Arduino/ESP32 libraries for network connectivity and service discovery.
    *   **`Vector`**: A C++ standard library container used for dynamic arrays (like the log buffer).

## Example Scenarios

Here are some common development workflows and the minimal sequence of commands to execute them:

**Scenario 1: Making a change to core C++ code (e.g., in `PHApp.cpp` or a `Component`)**

1.  Make your code changes.
2.  Compile and upload the new firmware:
    ```bash
    npm run upload
    ```
3.  Monitor the device for logs/output:
    ```bash
    npm run build:monitor 
    ```
    (Press Ctrl+C to exit the monitor)

**Scenario 2: Adding a new Component (`MyNewSensor`)**

1.  Follow the steps in "Steps to Add a New Component" above (define addresses, create class, implement logic, integrate into `PHApp`, cleanup).
2.  Compile and upload the new firmware:
    ```bash
    npm run upload
    ```
3.  Test the new component (e.g., using Modbus or serial commands):
    ```bash
    # Example: Read a holding register associated with the new component
    npm run modbus:read:holding -- --address <YOUR_NEW_COMPONENT_ADDRESS>
    
    # Monitor serial output
    npm run build:monitor
    ```

**Scenario 3: Changing the web UI (e.g., editing `front/index.html` or `front/styles.css`)**

1.  Make your changes to the files in the `front/` directory.
2.  Rebuild the web assets and the firmware:
    ```bash
    npm run web:build
    ```
3.  Upload the updated filesystem image:
    ```bash
    npm run web:uploadfs
    ```
4.  Upload the firmware (optional, but good practice if `web:build` included firmware changes):
    ```bash
    npm run upload 
    ```
5.  Access the web UI in your browser (e.g., `http://modbus-esp32.local`) and hard refresh (Ctrl+Shift+R or Cmd+Shift+R) to see changes.

**Scenario 4: Testing a specific Modbus register**

1.  Read the register:
    ```bash
    npm run modbus:read:holding -- --address <REGISTER_ADDRESS>
    ```
2.  Write to the register:
    ```bash
    npm run modbus:write:holding -- --address <REGISTER_ADDRESS> --value <NEW_VALUE>
    ```
3.  Read again to verify:
    ```bash
    npm run modbus:read:holding -- --address <REGISTER_ADDRESS>
    ```

**Scenario 5: Debugging with logs**

1.  Ensure the device is running and connected to the network.
2.  Fetch logs via the REST API:
    ```bash
    npm run debug:serial
    ```
3.  Alternatively, view live serial output:
    ```bash
    npm run build:monitor
    ```

## Core Code / Build

Commands related to basic compilation, cleaning, and uploading the main firmware code.

*   `npm run build`: Compiles the firmware using PlatformIO (`pio run`).
*   `npm run build:clean`: Cleans the build artifacts (`pio run -t clean`).
*   `npm run upload`: Compiles and uploads the firmware via the default upload method (`pio run -t upload`).
*   `npm run build:run`: A full cycle: compiles, uploads, and opens the serial monitor (`pio run && pio run -t upload && pio device monitor`).

## Web Assets

Commands related to generating, building, and uploading the web interface assets (HTML, CSS, Swagger).

*   `npm run web:gen-swagger`: Generates the `swagger_content.h` header file from `swagger.yaml`.
*   `npm run web:build`: Generates web assets (Swagger header, HTML/CSS headers) and then runs the main firmware build (`npm run build`).
*   `npm run web:uploadfs`: Uploads the LittleFS filesystem image containing web assets (`pio run -t uploadfs`). Use after `web:build` to update the UI.

## Modbus

Commands specifically for interacting with or testing Modbus functionality.

*   `npm run modbus:read:coil`: Reads Modbus coils.
*   `npm run modbus:read:holding`: Reads Modbus holding registers.
*   `npm run modbus:write:coil`: Writes to a Modbus coil.
*   `npm run modbus:write:holding`: Writes to a Modbus holding register.
*   `npm run test:modbus:counter:read`: Reads the battle counter value via Modbus.
*   `npm run test:modbus:counter:watch`: Continuously reads the battle counter value via Modbus.
*   `npm run test:modbus:counter:reset`: Resets the battle counter via Modbus.
*   `npm run test:modbus:counter:increment`: Increments the battle counter via Modbus.

## Serial Communication

Commands for interacting with the device via the serial port.

*   `npm run serial:send-cmd`: Sends a specific, hardcoded `printRegisters` command via serial.
*   `npm run serial:send`: Sends a generic message defined in `scripts/send_message.py` via serial.
*   `npm run test:serial:counter:increment`: Sends a command to increment the test counter via serial.
*   `npm run test:serial:counter:reset`: Sends a command to reset the test counter via serial.
*   `npm run test:serial:counter:get`: Sends a command to get the test counter value via serial.
*   `npm run test:serial:client-stats:reset`: Resets Modbus client statistics via serial command.
*   `npm run test:serial:client-stats:get`: Gets Modbus client statistics via serial command.

## REST API

Commands for testing the REST API endpoints.

*   `npm run test:api`: Runs a general REST API test suite.
*   `npm run test:api:ip`: Runs the general API test suite against a specific IP.
*   `npm run test:api:working`: Runs a basic "is the API working" test.
*   `npm run test:api:system-info`: Tests the `/api/v1/system/info` endpoint.
*   `npm run test:api:system-info:ip`: Tests the system info endpoint against a specific IP.
*   `npm run test:api:logs`: Tests the `/api/v1/system/logs` endpoint.
*   `npm run test:api:logs:ip`: Tests the logs endpoint against a specific IP.

## Performance / Stress Testing

Commands explicitly designed for performance or stress testing.

*   `npm run test:serial:rate`: Tests the rate of serial command processing.
*   `npm run test:serial:stress`: Performs a stress test with varying delays for serial commands.
*   `npm run test:modbus:battle`: Runs a Modbus read/write battle test.
*   `npm run test:modbus:battle:quick`: Runs a shorter version of the battle test.
*   `npm run test:modbus:battle:full`: Runs a longer, more intensive version of the battle test.
*   `npm run test:modbus:multi-client`: Tests handling multiple concurrent Modbus clients.
*   `npm run test:modbus:multi-client:low`: Runs the multi-client test with fewer clients/operations.
*   `npm run test:modbus:multi-client:high`: Runs the multi-client test with more clients/operations.
*   `npm run test:modbus:client-sequential`: Tests sequential connections from multiple Modbus clients.
*   `npm run test:modbus:client-sequential:max`: Tests sequential connections with the maximum configured clients.
*   `npm run test:modbus:longpoll`: Runs a long polling test for Modbus.

## Debugging / Monitoring

Commands useful for monitoring the device and diagnosing issues.

*   `npm run build:monitor`: Opens the PlatformIO serial monitor (`pio device monitor`).
*   `npm run debug:serial`: Fetches and prints the buffered logs from the device's REST API (`/api/v1/system/logs`).
*   `npm run test:modbus:counter:watch`: Continuously reads the battle counter value via Modbus.

## Documentation

Commands related to generating documentation.

*   `npm run docs:generate`: Generates code documentation using Doxygen.

## General

*   `npm test`: Placeholder script, currently does nothing specific (`echo "Error: no test specified" && exit 1`). 
*   

6.  **Build:** Add your new `.cpp` file to the build system if necessary (PlatformIO typically picks up source files in `src` automatically). Run `npm run build` to compile.

## Key Packages and Libraries

This project relies on several key software packages and libraries:

*   **PlatformIO**: The core build system and development ecosystem used to manage the toolchain, libraries, building, and uploading for the ESP32.
*   **Arduino Framework (for ESP32)**: Provides a simplified C++ API for interacting with the ESP32 hardware (GPIO, Serial, WiFi, etc.). It runs on top of ESP-IDF.
*   **ESP-IDF (Espressif IoT Development Framework)**: The official low-level development framework from Espressif, providing the drivers and core system functionalities.
*   **npm**: Used as a task runner to execute build, test, and utility scripts defined in `package.json`.
*   **Python**: Used for various helper scripts (located in the `scripts/` directory) for testing, sending commands, and interacting with the device over serial, Modbus, or HTTP.
*   **C++ Libraries (managed by PlatformIO):**
    *   **`ArduinoJson`**: For efficient JSON serialization and deserialization, used heavily in the REST API.
    *   **`eModbus`**: Handles Modbus RTU/TCP client and server communication.
    *   **`ArduinoLog`**: Provides flexible logging capabilities, including log levels and output redirection (used here for both Serial and the internal log buffer).
    *   **`LittleFS`**: A lightweight filesystem used to store web assets (HTML, CSS, etc.) on the ESP32's flash memory.
    *   **`WiFi` / `ESPmDNS`**: Standard Arduino/ESP32 libraries for network connectivity and service discovery.
    *   **`Vector`**: A C++ standard library container used for dynamic arrays (like the log buffer).

## Example Scenarios
// ... existing code ...

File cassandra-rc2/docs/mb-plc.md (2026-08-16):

# Comparison: Modbus Logic Engine (MB_SCRIPT) vs. PLC Ladder Logic

## 1. Introduction

This document compares the custom Modbus Logic Engine (`MB_SCRIPT`) implemented in this firmware with traditional PLC (Programmable Logic Controller) programming languages, primarily focusing on Ladder Logic (LD).

*   **Modbus Logic Engine (MB_SCRIPT):** A feature enabling simple, rule-based automation directly within the ESP32 firmware. Rules are configured and monitored via Modbus registers. It allows defining conditions based on Modbus values and triggering actions like writing Modbus values or calling internal C++ functions.
*   **PLC Ladder Logic (LD):** A graphical programming language widely used in industrial automation. It mimics the appearance of electrical relay logic diagrams, making it intuitive for electricians and technicians. It runs on dedicated PLC hardware in a cyclic scan execution model.

## 2. Core Concepts Comparison

| Feature | PLC Ladder Logic (Typical) | Modbus Logic Engine (MB_SCRIPT) |
| :--- | :--- | :--- |
| **Programming Model** | Graphical (Relay Logic Diagram), Textual (ST, FBD often avail.) | Rule-Based (IF condition THEN action), Configuration via Registers |
| **Representation** | Rungs, Contacts (NO/NC), Coils, Function Blocks (Timers, Cnt) | Blocks of Holding Registers defining rules |
| **Execution Model** | Cyclic Scan (Read Inputs -> Solve Logic -> Write Outputs) | Iterative `loop()` checks rules sequentially based on interval |
| **Data Addressing** | Standardized I/O points (%I, %Q), Memory (%M), Data Regs (%MW) | Modbus Addresses (Coils/Registers) managed by firmware components |
| **Built-in Functions**  | Timers (TON/TOF), Counters (CTU/CTD), Math, Compare, Move | Basic Comparisons (==, !=, <, >...), Write Coil/Reg, Call Method |
| **Complex Logic** | Subroutines, Jumps, Structured Text (ST), Function Blocks | Requires registering custom C++ methods (`CallableMethod`) |
| **Configuration Tool**  | Dedicated PLC IDE (e.g., TIA Portal, RSLogix) | Standard Modbus Client/Master Software |
| **Deployment** | Download program binary to PLC hardware | Write configuration values to Modbus registers |
| **Debugging/Monitor** | Online monitoring in IDE, Forcing I/O, Status LEDs | Reading Status registers via Modbus, Serial Logs (Debug/Receipt Flags) |
| **Hardware** | Dedicated Industrial PLC Hardware | Runs on the ESP32 microcontroller within the firmware |
| **Extensibility** | Adding I/O modules, using advanced function blocks, libraries | Adding/Registering C++ methods, potentially modifying engine code |
| **Target User** | Automation Engineers, Technicians, Electricians | Firmware developers, System integrators familiar with Modbus |

## 3. Detailed Comparison

### 3.1. Programming Model & Representation

*   **Ladder Logic:** Visual and intuitive for those familiar with electrical schematics. Logic flows left-to-right across rungs. Standard symbols for contacts, coils, timers, etc., are well-understood in the industry.
*   **MB_SCRIPT:** Abstract. Logic is defined by setting numerical values in specific Modbus registers according to predefined offsets (`ModbusLogicEngineOffsets`). Requires understanding the specific register map and enum values (`E_RegType`, `ConditionOperator`, `CommandType`, `MB_Error`). Less visual and more data-entry focused.

### 3.2. Execution

*   **Ladder Logic:** Typically deterministic cyclic scan. The PLC reads all inputs, executes the entire ladder program from top to bottom, and then updates all outputs in a predictable cycle time.
*   **MB_SCRIPT:** Executes within the ESP32's main `loop()`. Rules are checked sequentially within the `ModbusLogicEngine::loop()` call, which runs periodically based on `loopInterval`. Execution time can be influenced by other tasks running on the ESP32. It's event-driven based on Modbus value changes *observed* during rule evaluation, but the evaluation itself is interval-based.

### 3.3. Data Handling

*   **Ladder Logic:** Uses well-defined memory areas for inputs, outputs, internal bits, timers, counters, and data registers, accessed via standardized addressing.
*   **MB_SCRIPT:** Relies entirely on the existing Modbus address space managed by other firmware components (`ModbusManager`). Condition sources and action targets are arbitrary Modbus addresses. Internal rule state (status, timestamp, count) is exposed via dedicated status registers within the rule's block. Complex data manipulation requires C++ functions.

### 3.4. Capabilities & Functionality

*   **Ladder Logic:** Offers standard, pre-built function blocks for common automation tasks like timing delays, counting events, basic arithmetic, and data manipulation. More advanced PLCs include PID loops, communication protocols, motion control, etc.
*   **MB_SCRIPT:** Provides fundamental building blocks: compare Modbus values and trigger simple actions (write Modbus value, call internal function). It lacks built-in timers, counters, or complex math operations within the rule definition itself. Such functionality must be implemented in C++ and exposed via the `CALL_COMPONENT_METHOD` command.

### 3.5. Configuration & Deployment

*   **Ladder Logic:** Requires specialized, often vendor-specific, programming software. The compiled logic is downloaded as a binary program to the PLC. Configuration is done offline in the IDE.
*   **MB_SCRIPT:** Configured "online" by writing values to Modbus registers using any standard Modbus master tool. No separate compilation or download step for the logic itself is needed (only for the firmware containing the engine). This allows dynamic reconfiguration without reflashing firmware (though registered methods are fixed in firmware).

### 3.6. Debugging & Monitoring

*   **Ladder Logic:** IDEs provide powerful online monitoring tools, allowing visualization of rung state, live value tracing, and forcing of inputs/outputs for testing. PLCs often have hardware status LEDs.
*   **MB_SCRIPT:** Debugging relies on reading the `LAST_STATUS`, `LAST_TRIGGER_TS`, and `TRIGGER_COUNT` registers via Modbus. More detail requires enabling the `RULE_FLAG_DEBUG` and `RULE_FLAG_RECEIPT` flags and monitoring the device's serial output (`npm run build:monitor`). Less interactive than typical PLC debugging.

## 4. Strengths & Weaknesses

**MB_SCRIPT:**

*   **Strengths:**
    *   Simple rule structure, easy to understand if the register map is known.
    *   Configuration via standard Modbus tools - no specialized IDE needed.
    *   Runs directly on the ESP32, reducing need for external micro-controllers for simple logic.
    *   Extensible via C++ (`CALL_COMPONENT_METHOD`) for complex custom actions.
    *   Logic configuration can potentially be updated without firmware reflash.
*   **Weaknesses:**
    *   Limited built-in functions (no timers, counters, complex math within rules).
    *   Logic representation is abstract (register values) and not visual.
    *   Debugging relies heavily on Modbus reads and serial logs.
    *   Sequential rule execution might have timing implications compared to cyclic scan.
    *   Scalability limited by `MAX_LOGIC_RULES` and ESP32 resources.
    *   Complex logic requires C++ development and method registration.

**PLC Ladder Logic:**

*   **Strengths:**
    *   Visual and intuitive programming paradigm (especially LD).
    *   Industry standard, widely understood by technicians and engineers.
    *   Rich set of built-in standard functions (timers, counters, etc.).
    *   Mature, powerful IDEs with excellent online monitoring and debugging capabilities.
    *   Deterministic execution (typically).
    *   Highly scalable with modular hardware.
*   **Weaknesses:**
    *   Requires dedicated, often expensive, PLC hardware.
    *   Requires specialized, often expensive, vendor-specific IDE software.
    *   Less straightforward to integrate directly with custom C++ functions or device-specific hardware features compared to code running *on* the device.
    *   Configuration/updates typically require offline editing and download.

## 5. Use Cases

*   **MB_SCRIPT is suitable for:**
    *   Simple, reactive logic based directly on Modbus values on the device.
    *   Triggering predefined C++ functions based on Modbus conditions.
    *   Implementing basic interlocks or sequences configurable via Modbus.
    *   Situations where adding a full PLC is overkill or impractical.
    *   Environments where configuration via standard Modbus tools is preferred.
*   **PLC Ladder Logic is suitable for:**
    *   Complex industrial automation and control sequences.
    *   Applications requiring standard timing, counting, and process control functions.
    *   Systems needing robust, deterministic execution.
    *   Environments where technicians are primarily familiar with Ladder Logic.
    *   Large-scale systems with extensive I/O requirements.

## 6. Conclusion

The Modbus Logic Engine (`MB_SCRIPT`) provides a useful, lightweight mechanism for implementing simple, Modbus-driven automation rules directly on the ESP32 firmware. It leverages the existing Modbus infrastructure for configuration and interaction but relies on C++ for complex actions. It is not a replacement for a full PLC system using Ladder Logic, which offers a more comprehensive, standardized, and visually intuitive environment with richer built-in capabilities tailored for industrial control, albeit with the requirement of dedicated hardware and software. The choice depends on the complexity of the required logic, the target environment, user expertise, and integration needs.

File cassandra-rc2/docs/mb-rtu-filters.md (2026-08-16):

# Modbus RTU Operation Filtering

The Modbus RTU filter system uses a **Chain of Responsibility** pattern to process `ModbusOperation`s before they are added to the execution queue. This allows for modular validation, modification, and management of operations.

## Architecture

Each filter implements the `ModbusOperationFilter` interface. The `process(ModbusOperation &op)` method passes the operation through the current filter's `filter()` logic and, if successful, forwards it to the next filter in the chain.

### Filter Interface

```cpp
class ModbusOperationFilter {
    // ...
    // Process the operation through this filter and subsequent filters
    bool process(ModbusOperation &op) {
        if (!filter(op)) return false; // Stop if this filter rejects
        if (nextFilter) return nextFilter->process(op); // Pass to next
        return true; // End of chain, accepted
    }

    // Abstract method to be implemented by concrete filters
    virtual bool filter(ModbusOperation &op) = 0;
};
```

## Active Filters

The current filter chain is configured in `ModbusRTU` constructor as follows:
1.  **DuplicateOperationFilter**
2.  **OperationLifecycleFilter**
3.  **PriorityFilter**

### 1. DuplicateOperationFilter
**Purpose**: Prevents the queue from filling up with identical requests.
**Logic**: Checks if an operation with the same `type`, `slaveId`, `address`, and `value` (for writes) is already pending in the `ModbusRTU` queue.
**Action**: Returns `false` (drops operation) if a duplicate is found.

### 2. OperationLifecycleFilter
**Purpose**: Enforces operation validity limits.
**Logic**: Checks if `op.retries` has exceeded `maxRetries`.
**Action**: Returns `false` (drops operation) if limits are exceeded.

### 3. PriorityFilter
**Purpose**: Dynamically assigns priority to operations based on device-specific logic.
**Logic**:
1.  Retrieves the target `RTU_Base` device instance using `Manager::getDeviceById(slaveId)`.
2.  Calls `device->isHighPriority(op)` to ask the device if this specific operation is critical.
3.  If `true`, sets the `OP_HIGH_PRIORITY_BIT` on the operation.
**Action**: Always returns `true` (modifies operation but doesn't drop it).

## Flow Diagram

```mermaid
sequenceDiagram
    participant Caller
    participant ModbusRTU
    participant DupFilter as DuplicateOperationFilter
    participant LifeFilter as OperationLifecycleFilter
    participant PrioFilter as PriorityFilter
    participant Device as RTU_Base (Device)

    Caller->>ModbusRTU: queueOperation(op)
    ModbusRTU->>DupFilter: process(op)
    
    rect rgb(240, 240, 240)
        Note right of DupFilter: Check for duplicates
        DupFilter->>DupFilter: filter(op)
    end
    
    alt Duplicate Found
        DupFilter-->>ModbusRTU: false (Drop)
    else Unique
        DupFilter->>LifeFilter: process(op)

        rect rgb(240, 240, 240)
            Note right of LifeFilter: Check Lifecycle
            LifeFilter->>LifeFilter: filter(op)
            Note right of LifeFilter: Check retries < max
        end

        alt Limit Exceeded
            LifeFilter-->>DupFilter: false
            DupFilter-->>ModbusRTU: false (Drop)
        else OK
            LifeFilter->>PrioFilter: process(op)
            
            rect rgb(240, 240, 240)
                Note right of PrioFilter: Check Priority
                PrioFilter->>PrioFilter: filter(op)
                PrioFilter->>Device: isHighPriority(op)
                Device-->>PrioFilter: bool
                opt isHighPriority == true
                    PrioFilter->>PrioFilter: op.setHighPriority(true)
                end
            end

            PrioFilter-->>LifeFilter: true
            LifeFilter-->>DupFilter: true
            DupFilter-->>ModbusRTU: true (Queue)
        end
    end
```

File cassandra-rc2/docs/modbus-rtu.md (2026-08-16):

# Modbus RTU Client Subsystem Documentation

## Overview

This document describes the classes, structures, and enums involved in the Modbus RTU Client functionality within the firmware. This subsystem is primarily managed by the `ModbusRTU` class and is responsible for communicating with downstream Modbus RTU slave devices over a serial (RS485) connection. It often works in conjunction with the Modbus TCP server (`ModbusManager`) to act as a TCP-to-RTU gateway.

The core tasks include queuing read/write operations, managing communication timing, handling retries and errors, caching slave data, and providing an interface to interact with the RTU devices.

## Key Classes

### `ModbusRTU`

*   **Header:** `src/ModbusRTU.h`
*   **Source:** `src/ModbusRTU.cpp`
*   **Purpose:** The central class managing Modbus RTU client communication. It uses the `eModbus` library's `ModbusClientRTU` internally.
*   **Responsibilities:**
    *   Initializes the RTU client and serial port.
    *   Manages a queue (`operationQueue`) of pending `ModbusOperation` requests.
    *   Handles the execution of operations, respecting timing intervals (`minOperationInterval`).
    *   Processes responses and errors from the `eModbus` library via callbacks (`onDataReceived`, `onErrorReceived`).
    *   Maintains a cache (`slaveData`) of the last known values for registers and coils on each slave device using `SlaveData` and `ModbusValueEntry`.
    *   Provides public methods (`readCoil`, `writeRegister`, etc.) to queue operations.
    *   Manages an optional filter chain (`ModbusOperationFilter`) to preprocess outgoing operations (e.g., prevent duplicates, rate limit).
    *   Provides status information (error counts, success rates).
    *   Handles adaptive timing adjustments if `ENABLE_ADAPTIVE_TIMEOUT` is defined.

### `BaseModbusDevice`

*   **Header:** `src/ModbusTypes.h`
*   **Source:** `src/ModbusTypes.cpp`
*   **Purpose:** Represents the state and basic interaction logic for a single external Modbus RTU slave device being managed by `ModbusRTU`.
*   **Responsibilities:**
    *   Stores the slave ID (`deviceId`).
    *   Tracks the device's communication state (`E_DeviceState`: IDLE, RUNNING, ERROR).
    *   Manages communication timing (timeout, sync interval) and error counts for the specific device.
    *   Holds collections (`inputRegisters`, `outputRegisters`) of `RegisterState` objects representing the data points on the slave.
    *   Provides methods to add/manage `RegisterState` objects (`addInputRegister`, `addOutputRegister`).
    *   Provides methods to interact with the device's registers via the `ModbusRTU` manager (`initialize`, `syncFromDevice`, `writeOutputs`).
    *   Provides local accessors for register values (`getInputRegisterValue`, `getOutputRegisterValue`, `setOutputRegisterValue`).
    *   Includes helper methods for state management (`printState`, `reset`, `runTestSequence`).

### `ModbusDeviceState`

*   **Header:** `src/ModbusDeviceState.h`
*   **Source:** `src/ModbusDeviceState.cpp`
*   **Purpose:** A derived class of `BaseModbusDevice`. Intended for application-specific implementations or specializations of Modbus RTU slave devices.
*   **Responsibilities:**
    *   Currently, mainly overrides `setState` to add specific logging.
    *   Its constructor can be used to add specific default registers required by the application logic using the `addInputRegister`/`addOutputRegister` methods inherited from `BaseModbusDevice`.

### `RegisterState`

*   **Header:** `src/ModbusTypes.h`
*   **Source:** `src/ModbusTypes.cpp`
*   **Purpose:** Represents a single data point (Input Register, Holding Register, Coil, or Discrete Input) on an external Modbus RTU slave device.
*   **Responsibilities:**
    *   Stores the register type (`RegType`), Modbus address, current value, min/max values (for validation), and priority.
    *   Provides methods (`readFromDevice`, `writeToDevice`) to queue corresponding read/write operations via the `ModbusRTU` manager.
    *   Includes helper methods for boolean conversion (`getBoolValue`, `setBoolValue`) and printing state (`printState`).

## Supporting Structures

### `ModbusOperation`

*   **Header:** `src/ModbusTypes.h`
*   **Purpose:** Represents a single Modbus read or write request waiting to be executed or currently in progress. Stored in the `ModbusRTU`'s `operationQueue`.
*   **Key Members:**
    *   `timestamp`: When the operation was created.
    *   `token`: Unique identifier used by `eModbus` library for asynchronous handling.
    *   `address`, `value`, `quantity`: Modbus request parameters.
    *   `slaveId`: Target slave device.
    *   `type`: The type of operation (`E_MB_OpType`).
    *   `status`: Current status (`E_MB_OpStatus`: PENDING, SUCCESS, FAILED, RETRYING).
    *   `retries`: Number of times execution has been attempted.
    *   `flags`: Bit flags indicating state (USED, HIGH_PRIORITY, IN_PROGRESS, BROADCAST, SYNCHRONIZED).

### `ModbusValueEntry`

*   **Header:** `src/ModbusTypes.h`
*   **Purpose:** Represents a cached value for a single register or coil address on a specific slave. Used within the `SlaveData` structure.
*   **Key Members:**
    *   `address`: The Modbus address.
    *   `value`: The last known value.
    *   `lastUpdate`: Timestamp of the last update.
    *   `synchronized`: Flag indicating if the cached value is believed to be in sync with the device.
    *   `used`: Flag indicating if this entry is actively used.

### `SlaveData`

*   **Header:** `src/ModbusTypes.h`
*   **Purpose:** Holds the cached data for a single Modbus RTU slave device managed by `ModbusRTU`. An array of `SlaveData` is stored in `ModbusRTU`.
*   **Key Members:**
    *   `coils`: Fixed-size array of `ModbusValueEntry` for coils.
    *   `registers`: Fixed-size array of `ModbusValueEntry` for registers.
    *   `coilCount`, `registerCount`: Number of used entries in the arrays.

## Operation Filtering

### `ModbusOperationFilter` (Base Class)

*   **Header:** `src/ModbusTypes.h`
*   **Purpose:** Abstract base class for filters that can be chained together to process `ModbusOperation` requests before they are queued for execution by `ModbusRTU`.
*   **Key Methods:**
    *   `filter(op)`: Pure virtual method; derived classes implement logic here. Returns `true` to allow the operation, `false` to drop it.
    *   `process(op)`: Processes the operation through the current filter and the rest of the chain.
    *   `setNext(filter*)`, `getNext()`: Manage the filter chain links.
    *   `notifyOperationExecuted(op)`, `notifyOperationCompleted(op)`: Optional methods for stateful filters.
    *   `getType()`: Returns the filter type (`E_FilterType`).

### Derived Filter Classes

*   **Header:** `src/ModbusTypes.h`
*   **Source:** `src/ModbusTypes.cpp`
*   **Classes:**
    *   `DuplicateOperationFilter`: Prevents queuing an operation if an identical one (same slave, type, address) is already pending in the `ModbusRTU` queue. Requires a pointer to the `ModbusRTU` instance.
    *   `RateLimitFilter`: Enforces a minimum time interval between consecutive operations passing through it.
    *   `PriorityFilter`: Currently a placeholder; intended to potentially adjust operation priority flags (though filtering itself always returns true).
    *   `OperationLifecycleFilter`: Drops operations that have exceeded `MAX_RETRIES` or have timed out (`OPERATION_TIMEOUT`).

## Key Enums

*   **`E_MB_OpType`**: (`src/ModbusTypes.h`) Defines the type of Modbus operation (READ_COIL, WRITE_REGISTER, etc.).
*   **`E_MB_OpStatus`**: (`src/ModbusTypes.h`) Defines the status of a queued `ModbusOperation` (PENDING, SUCCESS, FAILED, RETRYING).
*   **`MB_Error`**: (`src/ModbusTypes.h`) Comprehensive error codes, combining standard Modbus exceptions, internal queue/operation errors, and `eModbus` communication errors.
*   **`E_FilterType`**: (`src/ModbusTypes.h`) Identifies the type of a `ModbusOperationFilter`.
*   **`E_DeviceState`**: (`src/ModbusTypes.h`) State of a `BaseModbusDevice` (IDLE, RUNNING, ERROR).
*   **`RegType`**: (`src/ModbusTypes.h`) Type of a `RegisterState` (INPUT, HOLDING, COIL, DISCRETE_INPUT).
*   **`E_InitState`**: (`src/ModbusRTU.h`) Internal state for the `ModbusRTU` class initialization process.

## Key Constants

*   **`MAX_MODBUS_SLAVES`**: (`src/ModbusTypes.h`) Max number of RTU slaves the client can manage.
*   **`MAX_ADDRESSES_PER_SLAVE`**: (`src/ModbusTypes.h`) Size of the `ModbusValueEntry` arrays within `SlaveData`.
*   **`MAX_PENDING_OPERATIONS`**: (`src/ModbusTypes.h`) Size of the `ModbusRTU` operation queue.
*   **`MAX_RETRIES`**: (`src/ModbusTypes.h`) Default max retries for a failing operation.
*   **`OPERATION_TIMEOUT`**: (`src/ModbusTypes.h`) Default timeout for an operation before being considered failed/expired by `OperationLifecycleFilter`.
*   **`BAUDRATE`**: (`src/ModbusTypes.h`) Default serial baud rate for RS485.
*   **`PRIORITY_*` Defines**: (`src/ModbusTypes.h`) Constants used for setting `RegisterState` priorities.
*   **`OP_FLAG_*` Defines**: (`src/ModbusTypes.h`) Bit flags used within `ModbusOperation.flags`.

## Callback Functions

*   **`ResponseCallback`**: (`src/ModbusTypes.h`) typedef `void (*ResponseCallback)(uint8_t slaveId)`. Can be set on `ModbusRTU` to trigger custom logic when *any* response (success or error) is received for a slave.
*   **`OnRegisterChangeCallback`**: (`src/ModbusTypes.h`) typedef `void (*OnRegisterChangeCallback)(const ModbusOperation& op, uint16_t oldValue, uint16_t newValue)`. Set on `ModbusRTU` to be notified when a successful read operation results in a changed value in the cache.
*   **`OnWriteCallback`**: (`src/ModbusTypes.h`) typedef `void (*OnWriteCallback)(const ModbusOperation& op)`. Set on `ModbusRTU` to be notified when a write operation completes successfully.
*   **`OnErrorCallback`**: (`src/ModbusTypes.h`) typedef `void (*OnErrorCallback)(const ModbusOperation& op, int errorCode, const char* errorMessage)`. Set on `ModbusRTU` to be notified when an operation fails (either timeout, Modbus exception, or internal error).

## Mermaid Diagrams

### Core Class Relationships

```mermaid
classDiagram
    class ModbusRTU {
        +MB_Error begin(HardwareSerial&, uint32_t)
        +MB_Error process()
        +MB_Error readCoil(uint8_t, uint16_t)
        +MB_Error writeRegister(uint8_t, uint16_t, uint16_t)
        +bool getCoilValue(uint8_t, uint16_t, bool&)
        +bool getRegisterValue(uint8_t, uint16_t, uint16_t&)
        +bool isCoilSynchronized(uint8_t, uint16_t)
        +bool isRegisterSynchronized(uint8_t, uint16_t)
        +bool hasPendingOperations(uint8_t)
        +void addFilter(ModbusOperationFilter*)
        -SlaveData slaveData[MAX_MODBUS_SLAVES]
        -ModbusOperation operationQueue[MAX_PENDING_OPERATIONS]
        -ModbusOperationFilter* firstFilter
        -MB_Error queueOperation(ModbusOperation, bool)
        -void onDataReceived(ModbusMessage, uint32_t)
        -void onErrorReceived(Error, uint32_t)
        -ModbusValueEntry* findCoilEntry(...)
        -ModbusValueEntry* createCoilEntry(...)
        -ModbusValueEntry* findRegisterEntry(...)
        -ModbusValueEntry* createRegisterEntry(...)
    }

    class BaseModbusDevice {
        +uint8_t deviceId
        +E_DeviceState state
        +unsigned long syncInterval
        +bool addInputRegister(uint16_t, uint8_t)
        +bool addOutputRegister(uint16_t, uint16_t, uint8_t)
        +void updateState(ModbusRTU&)
        +bool initialize(ModbusRTU&)
        +void syncFromDevice(ModbusRTU&)
        +void writeOutputs(ModbusRTU&)
        +void printState(ModbusRTU&)
        +void reset()
        +uint16_t getInputRegisterValue(uint16_t)
        +uint16_t getOutputRegisterValue(uint16_t)
        +void setOutputRegisterValue(uint16_t, uint16_t)
        #RegisterState* inputRegisters[]
        #RegisterState* outputRegisters[]
        #int inputRegCount
        #int outputRegCount
    }

    class ModbusDeviceState {
      +ModbusDeviceState(uint8_t)
      +void setState(E_DeviceState) override
    }

    class RegisterState {
        +RegType type
        +uint16_t address
        +uint16_t value
        +uint8_t priority
        +MB_Error readFromDevice(ModbusRTU&, uint8_t)
        +MB_Error writeToDevice(ModbusRTU&, uint8_t)
        +void printState(ModbusRTU&, uint8_t)
        +bool getBoolValue()
    }

    class ModbusOperation {
        +unsigned long timestamp
        +uint32_t token
        +uint16_t address
        +uint16_t value
        +uint16_t quantity
        +uint8_t slaveId
        +E_MB_OpType type
        +E_MB_OpStatus status
        +uint8_t flags
    }

    class SlaveData {
        #ModbusValueEntry coils[]
        #ModbusValueEntry registers[]
        #uint8_t coilCount
        #uint8_t registerCount
    }

    class ModbusValueEntry {
        +unsigned long lastUpdate
        +uint16_t address
        +uint16_t value
        +bool synchronized
        +bool used
    }

    ModbusRTU o-- "0..MAX_MODBUS_SLAVES" SlaveData : contains cache
    ModbusRTU o-- "0..MAX_PENDING_OPERATIONS" ModbusOperation : queues
    ModbusRTU ..> ModbusOperationFilter : uses chain
    BaseModbusDevice o-- "0..MAX_INPUT_REGISTERS" RegisterState : manages inputs
    BaseModbusDevice o-- "0..MAX_OUTPUT_REGISTERS" RegisterState : manages outputs
    BaseModbusDevice ..> ModbusRTU : interacts via
    ModbusDeviceState --|> BaseModbusDevice : inherits from
    SlaveData o-- "0..MAX_ADDRESSES_PER_SLAVE" ModbusValueEntry : caches coil values
    SlaveData o-- "0..MAX_ADDRESSES_PER_SLAVE" ModbusValueEntry : caches register values
    RegisterState ..> ModbusRTU : interacts via

```

### Filter Chain Relationships

```mermaid
classDiagram
    class ModbusOperationFilter {
        <<Abstract>>
        +process(ModbusOperation) bool
        +setNext(ModbusOperationFilter*)
        +getType() E_FilterType
        #ModbusOperationFilter* nextFilter
        +$ filter(ModbusOperation) bool
        +$ notifyOperationExecuted(ModbusOperation) void
        +$ notifyOperationCompleted(ModbusOperation) void
    }

    class DuplicateOperationFilter {
        +DuplicateOperationFilter(ModbusRTU*)
        +filter(ModbusOperation) bool
        -ModbusRTU* modbusRTU
    }

    class RateLimitFilter {
        +RateLimitFilter(ulong)
        +filter(ModbusOperation) bool
        -ulong minInterval
        -ulong lastOperationTime
    }

    class PriorityFilter {
        +filter(ModbusOperation) bool
        +adjustPriority(ModbusOperation&) bool
    }

    class OperationLifecycleFilter {
        +OperationLifecycleFilter(ulong, uint8_t)
        +filter(ModbusOperation) bool
        -ulong timeout
        -uint8_t maxRetries
    }

    DuplicateOperationFilter --|> ModbusOperationFilter
    RateLimitFilter --|> ModbusOperationFilter
    PriorityFilter --|> ModbusOperationFilter
    OperationLifecycleFilter --|> ModbusOperationFilter

```

---

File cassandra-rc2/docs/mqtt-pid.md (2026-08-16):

# PID Controller Logging via MQTT

This document outlines the setup for logging PID controller data to an InfluxDB instance via MQTT and how to visualize this data in Grafana.

## Firmware MQTT Setup

The firmware is configured to send PID controller data (Setpoint, Process Value, and heating state) to an MQTT broker. This data is then picked up by a Telegraf instance, which forwards it to InfluxDB.

### Enabling the Feature

To enable MQTT logging, ensure the following line is present and not commented out in `cassandra-rc2/src/config.h`:

```c++
#define ENABLE_MQTT_LOGGING
```

### MQTT Configuration

The MQTT broker details are configured in `cassandra-rc2/src/PHApp-Mqtt.cpp`. You may need to change the `MQTT_BROKER` IP address to match your environment.

```c++
#define MQTT_BROKER "192.168.1.100" // Replace with your MQTT broker's IP address
#define MQTT_PORT 1883
```

### Data Format

The firmware sends data using the InfluxDB Line Protocol. The format is as follows:

-   **Measurement:** `pid_controller`
-   **Tags:**
    -   `controller_id`: (integer) The ID of the PID controller (e.g., 1, 2, ... 8).
-   **Fields:**
    -   `sp`: (integer) The Setpoint value.
    -   `pv`: (integer) The Process Value.
    -   `heating`: (boolean) The heating state (`true` or `false`).

**Example Payload:**

```
pid_controller,controller_id=1 sp=150,pv=148,heating=true
```

This message is published to the topic `pid/controller/<id>`.

---

## Grafana: Adding InfluxDB Data Source

Follow these steps to connect your Grafana instance to the InfluxDB container.

1.  **Navigate to Grafana:** Open your web browser and go to `http://localhost:3000`.

2.  **Login:** Use the default credentials `admin` for both username and password, unless you have changed them. You will be prompted to change the password on first login.

3.  **Go to Data Sources:**
    *   In the left-hand menu, hover over the **Configuration** (cog) icon.
    *   Click on **Data Sources**.

4.  **Add Data Source:**
    *   Click the **"Add new data source"** button.
    *   Select **"InfluxDB"** from the list of time series databases.

5.  **Configure the Connection:**

    *   **Name:** Give your data source a name, for example, `InfluxDB_PID`.
    *   **Query Language:** Select **Flux**.
    *   **URL:** Set the URL to `http://influxdb:8086`. Grafana and InfluxDB are in the same Docker network, so they can communicate using their service names.
    *   **Authentication:** Leave the "Basic auth" and "With credentials" toggles off.
    *   **Organization:** Enter `my-org`.
    *   **Token:** Enter `my-super-token`.
    *   **Default Bucket:** Enter `my-bucket`.
    *   **Min time interval:** `10s` (optional, but good practice to match the Telegraf flush interval).

    The credentials and settings are derived from your `docker-compose.yaml` file:

    -   `DOCKER_INFLUXDB_INIT_USERNAME`: **admin**
    -   `DOCKER_INFLUXDB_INIT_PASSWORD`: **admin123**
    -   `DOCKER_INFLUXDB_INIT_ORG`: **my-org**
    -   `DOCKER_INFLUXDB_INIT_BUCKET`: **my-bucket**
    -   `DOCKER_INFLUXDB_INIT_ADMIN_TOKEN`: **my-super-token**

6.  **Save & Test:**
    *   Click the **"Save & test"** button at the bottom of the page.
    *   You should see a green notification saying "Data source is working".

You are now ready to create dashboards and query your PID controller data from InfluxDB in Grafana.

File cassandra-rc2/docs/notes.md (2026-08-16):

## ESP32 - LittleFS Size

https://community.platformio.org/t/how-to-define-littlefs-partition-build-image-and-flash-it-on-esp32/11333

https://github.com/earlephilhower/mklittlefs/releases

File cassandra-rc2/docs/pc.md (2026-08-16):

# PressCylinder – Bug & Undefined Behaviour Report

- **Division by zero**: `m_pvs[i]->update((_pvs_raw[i] * 100) / _settings.maxload_threshold)` (PressCylinder.cpp) is executed even when `maxload_threshold` is **0**. User‐supplied JSON can set this value to 0 because it's clamped in `[0, PRESS_CYLINDER_MAX_LOAD_CLAMP]`; clamp lower bound should be 1.

- **Stale PV values on sensor error**: `pvsOk()` returns `false` as soon as one `getWeight()` call fails, but previously read `_pvs_raw` entries remain unchanged. Subsequent logic (state machine, solenoid control, diagnostics) may consume these stale values.

- **`has_stalled()` uses the last cylinder only**: `last_pv` is overwritten inside the loop, so the stall check always compares every cylinder against the PV of the *last* valid cylinder, not the minimum/average as intended.

- **`min_pv` initialisation**: `uint32_t min_pv = -1` relies on unsigned wrap-around. If *no* loadcell is attached the diff check becomes `(max_pv - 0xFFFFFFFF)` which overflows. Guard with a counter of valid sensors.

- **Memory leak**: `m_pvs[i] = new PressCylinderValue(...)` is never deleted; add destructor or migrate to static allocation.

- **Unbalanced / balance flip timing**: In `MODE_AUTO_MULTI_BALANCED` the active cylinder flips every `BALANCE_INTERVAL` even if both PVs are already balanced (< `BALANCE_MIN_PV_DIFF`). Consider conditional flip only when imbalance persists.

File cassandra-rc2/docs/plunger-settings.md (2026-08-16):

# Plunger Settings

This document explains the settings you can change to control how the Plunger works. Think of it like a control panel for the Plunger. These settings are usually saved in a special file on the machine.

## 1. Speed Settings

This group of settings controls how fast or slow the Plunger moves. The speed is measured in Hertz (Hz), which is a way to describe motor speed. Sometimes, the number you see in the settings might be the actual Hz value multiplied by 100 (for example, a setting of 5000 means 50.00 Hz).

*   **1.1. Slow Speed** (`speedSlowHz`): This is the speed the Plunger uses when you're moving it up or down carefully, like when it's "homing" (returning to its starting position) slowly. Unit: Hz.
*   **1.2. Medium Speed** (`speedMediumHz`): A general-purpose medium speed. This might be used for standard operations if a more specific speed isn't set. Unit: Hz.
*   **1.3. Fast Speed** (`speedFastHz`): A general-purpose fast speed. This could be used when the Plunger needs to move quickly and a specific speed for that action isn't defined. Unit: Hz.
*   **1.4. Fill Plunge Speed** (`speedFillPlungeHz`): When the Plunger is in the "Filling Sequence" and moving downwards (plunging) to fill something, this is the speed it will use. Unit: Hz.
*   **1.5. Fill Home Speed** (`speedFillHomeHz`): During the "Filling Sequence," after the Plunger has moved down, it needs to return to its starting position (homing). This setting controls the speed for that upward movement. Unit: Hz.

## 2. Jam Detection & Timing Settings

These settings are all about how the Plunger detects if it's stuck (jammed) and how long it waits or operates in different situations.

*   **2.1. Jam Threshold Current** (`currentJamThresholdMa`): The Plunger knows it's jammed if the motor starts using too much electricity (current). This setting is the "too much" point. If the motor current goes above this value, the Plunger assumes it's stuck. Measured in milliamperes (mA).
*   **2.2. Jammed Duration - Homing** (`jammedDurationHomingMs`): When the Plunger is moving to its home position, if it thinks it's jammed, this is how long it will keep trying or stay in that jammed state before it stops or tries something else. Measured in milliseconds (ms).
*   **2.3. Jammed Duration - Operation** (`jammedDurationMs`): Similar to the above, but this is for when the Plunger is doing a general operation (not specifically homing). If it detects a jam, this is how long it considers itself jammed. Unit: ms.
*   **2.4. Max Universal Jam Time** (`maxUniversalJamTimeMs`): This is a safety feature. It's the absolute maximum time the Plunger will keep trying to push if it's jammed, no matter what it's doing. After this time, it will give up to prevent damage. Unit: ms.
*   **2.5. Auto Mode Hold Time** (`autoModeHoldDurationMs`): To start "Automatic Plunging" or "Automatic Homing," you need to hold the joystick UP or DOWN for a certain amount of time. This setting is that duration. (Default in User Manual: 3.5 seconds). Unit: ms.
*   **2.6. Fill Joystick Hold Time** (`fillJoystickHoldDurationMs`): To start the "Filling Sequence," you need to hold the joystick to the LEFT. This setting is how long you need to hold it. (Default in User Manual: 2.5 seconds). Unit: ms.
*   **2.7. Fill Plunged Wait Time** (`fillPlungedWaitDurationMs`): In the "Filling Sequence," after the Plunger moves down and senses it's full (jammed), it will wait for this amount of time before it starts moving up again. (Default in User Manual: 1.3 seconds). Unit: ms.
*   **2.8. Fill Homed Wait Time** (`fillHomedWaitDurationMs`): In the "Filling Sequence," after the Plunger has moved all the way up (homed), it waits for this duration before the sequence is totally finished and it's ready for a new command. (Default in User Manual: 1.5 seconds). Unit: ms.
*   **2.9. Record Hold Time** (`recordHoldDurationMs`): To start "Record Mode" (where you record how long a plunge takes), you need to hold the joystick to the RIGHT. This is how long you need to hold it to begin recording. (Default in User Manual: 3 seconds). Unit: ms.
*   **2.10. Max Record Duration** (`maxRecordDurationMs`): When you're recording a plunge, there's a maximum time it will record for. If you go over this time, it will stop recording automatically. (Default in User Manual: 20 seconds). Unit: ms.
*   **2.11. Default Replay Duration** (`replayDurationMs`): If you want to "Replay" a plunge but haven't recorded one yet, the Plunger will use this default amount of time for the plunge. (Default in User Manual: 4.5 seconds). Unit: ms.
*   **2.12. Max Operation Duration** (`defaultMaxOperationDurationMs`): This is another safety net. It sets a general maximum time for any single movement the Plunger makes (like one manual push or one part of the filling sequence). If a movement takes longer than this, it will be stopped. Unit: ms.

## 3. Post-Flow Settings

"Post-Flow" is an optional step that can happen after the Plunger replays a recorded movement. It might be a little extra push or movement.

*   **3.1. Enable Post Flow** (`enablePostFlow`): This is a simple on/off switch. If it's set to `true` (on), the post-flow sequence will happen after a replay. If `false` (off), it won't.
*   **3.2. Post Flow Duration** (`postFlowDurationMs`): If post-flow is enabled, this is how long the main pressing part of that sequence will last. Unit: ms.
*   **3.3. Post Flow Speed** (`postFlowSpeedHz`): This controls how fast the Plunger moves during the post-flow sequence. Unit: Hz.
*   **3.4. Post Flow Current Threshold** (`currentPostFlowMa`): Just like the main jam detection, this is the motor current level that tells the Plunger it's jammed specifically during the post-flow movement. Unit: mA.
*   **3.5. Post Flow Stopping Wait Time** (`postFlowStoppingWaitMs`): After the main replay finishes, the Plunger will wait for this amount of time *before* it starts the post-flow movement. Unit: ms.
*   **3.6. Post Flow Complete Wait Time** (`postFlowCompleteWaitMs`): After the post-flow movement is done and the motor has stopped, the Plunger waits for this amount of time before it goes back to its normal ready (IDLE) state. Unit: ms.

---

**Important Notes:**
*   The names in `backticks` (like `speedSlowHz`) are the technical names for these settings. You might see these in configuration files or if a technician is looking at the system.
*   **Units**:
    *   `ms`: milliseconds (1000 milliseconds = 1 second)
    *   `Hz`: Hertz (a measure of motor speed)
    *   `mA`: milliamperes (a measure of electrical current)
*   The "(User Manual: X seconds)" notes tell you what the Plunger User Manual says about that setting, usually the default time. The actual setting on your machine might be different if it has been changed.
*   For speeds in Hz, remember that the number in the settings file might be 100 times bigger than the actual Hz value (e.g., a setting of 2550 means 25.50 Hz).

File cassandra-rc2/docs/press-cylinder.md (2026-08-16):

# Press Cylinder Component Documentation

The `PressCylinder` component is a high-level controller for hydraulic or electric press cylinders. It manages the interaction between **Loadcells** (input sensors) and **Solenoids** (output actuators) to achieve precise pressure control. It supports single and dual-cylinder configurations with various manual and automated modes.

## Architecture

The component inherits from `NetworkComponent` and exposes its state and configuration via Modbus TCP. It integrates a `Joystick` and `PushButton` for efficient manual control and safety overrides.

```mermaid
classDiagram
    class NetworkComponent {
        +short id
        +mb_tcp_read()
        +mb_tcp_write()
    }
    class PressCylinder {
        +E_Mode mode
        +E_State state
        +loop()
        +loopSingle()
        +loopMulti()
    }
    class Loadcell {
        +getWeight()
    }
    class Solenoid {
        +setValue()
    }
    class Joystick {
        +getPosition()
    }

    NetworkComponent <|-- PressCylinder
    PressCylinder --> "1..2" Loadcell : Monitors
    PressCylinder --> "1..2" Solenoid : Controls
    PressCylinder --> "1" Joystick : Manual Input
```

## Interface (Modbus Registers)

| Name | Type | Description |
|---|---|---|
| **Target SP** | RW | Target setpoint for Auto modes (0-100% of Max Load). |
| **Mode** | RW | Operation mode (Manual, Auto, etc.). |
| **State** | RO | Current state (Idle, Pressing, MaxLoad, Error). |
| **Error Code** | RO | Specific error reason (Overload, Stalled, etc.). |
| **CFlags** | RW | Configuration flags (Safety checks enable/disable). |
| **OutputMode** | RW | Special output triggers (e.g., HOLD). |
| **Interlocked**| RW | boolean flag indicating system readiness/safety interlock. |

## Operational Modes

The component operates in one of several modes, determined by the `m_mode` register.

| Mode ID | Name | Description |
|---|---|---|
| 1 | **MANUAL** | Direct single-cylinder control via Joystick. |
| 2 | **AUTO** | Automatic single-cylinder press to Target SP. |
| 3 | **MANUAL_MULTI** | Direct dual-cylinder control (synchronized). |
| 4 | **AUTO_MULTI** | Automatic dual-cylinder press (simultaneous). |
| 5 | **AUTO_MULTI_BALANCED** | Automatic dual-cylinder press with load balancing. |

### State Machine Overview

The system transitions between high-level states based on safety checks and operation completion.

```mermaid
stateDiagram-v2
    IDLE --> PRESSING : Joystick UP or Auto Start
    PRESSING --> IDLE : Joystick DOWN or Target Reached
    PRESSING --> ERROR : Safety Violation
    PRESSING --> MAXLOAD : Load > Max Threshold
    ERROR --> IDLE : Reset Command
    MAXLOAD --> IDLE : Reset / Joystick Down
```

---

## Detailed Mode Logic

### 1. Manual Mode (Single & Multi)

In manual modes, the operator has direct control over the solenoids using the joystick.

* **Safety:** Stops immediately if `MAX_LOAD` is exceeded.
* **Response:** Joystick UP activates solenoid(s). Joystick DOWN/CENTER deactivates them.

**Pseudo Code:**

```python
if CheckMaxLoad(current_load):
    Stop()
    SetState(ERROR, OVERLOAD)
    return

if Joystick.Position == UP:
    Solenoid.On()
else:
    Solenoid.Off()
```

### 2. Auto Mode (Single)

Automatic pressing until a target load is reached. The solenoid remains active as long as the current load is below the target (minus deadband).

**Pseudo Code:**

```python
target_value = (MaxLoad * TargetSP_Percentage) / 100

if current_load < target_value:
    Solenoid.On()
else:
    Solenoid.Off()
```

### 3. Auto Multi (Simultaneous)

Both cylinders press simultaneously until the target is reached.

* **Stall Detection:** If solenoids are active but PV (load) doesn't increase, the system aborts.
* **Balance Safety:** If the difference between cylinders > `balance_max_pv_diff`, it aborts.

**Pseudo Code:**

```python
if Abs(Load_A - Load_B) > CriticalBalanceThreshold:
    TriggerError(BALANCE_MAX_DIFF)
    return

if DetectStall(Load_A, Load_B):
    TriggerError(STALLED)
    return

# Simple control: Press if below target
for cylinder in [A, B]:
    if cylinder.load < target_value:
        cylinder.Solenoid.On()
    else:
        cylinder.Solenoid.Off()
```

### 4. Auto Multi Balanced (Smart Balancing)

This is the most complex mode. It intelligently toggles cylinders to keep the load balanced while pressing. It prioritizes the cylinder with the *lowest* load to "catch up".

**Core Logic:**

1. **Check Balance:** Is the difference between cylinders within the acceptable deadband?
2. **Unbalanced Strategy:** Ignore the higher loaded cylinder. Actively press ONLY the cylinder with the lowest load to correct the imbalance.
3. **Balanced Strategy:** If balanced, toggle between cylinders periodically (e.g., every 3 seconds) or press both if perfectly matched, to maintain forward progress without creating new imbalances.
4. **Auto Advance:** If the system is balanced and making progress, the "Auto Timeout" timer is reset prevents nuisance timeouts during long press cycles.

**Flowchart:**

```mermaid
graph TD
    Start[Start Loop] --> CheckSafety[Check Safety Limit Balance/Stall]
    CheckSafety -- Error --> ErrorState[Error State]
    CheckSafety -- OK --> CalcDiff[Calculate Load Difference]
    
    CalcDiff --> IsBalanced{Difference < Deadband?}
    
    IsBalanced -- No (Unbalanced) --> FindLowest[Identify Cylinder with Lowest Load]
    FindLowest --> PressUrgent[Activate Lowest Load Cylinder ONLY]
    PressUrgent --> StopOthers[Deactivate Other Cylinder]
    
    IsBalanced -- Yes (Balanced) --> TimerCheck{Switch Interval Elapsed?}
    TimerCheck -- Yes --> Toggle[Switch Active Cylinder]
    TimerCheck -- No --> KeepActive[Keep Current Active Cylinder]
    
    Toggle --> DriveBalanced[Activate Selected Cylinder]
    KeepActive --> DriveBalanced
```

**Pseudo Code (Balanced):**

```python
min_load = Min(Load_A, Load_B)
max_load = Max(Load_A, Load_B)

# Safety Checks
if HasStalled(min_load): Abort(STALLED)
if (max_load - min_load) > MaxSafetyDiff: Abort(BALANCE_ERROR)

# Control Logic
if (max_load - min_load) > Deadband:
    # UNBALANCED: Catch up logic
    urgent_cylinder = CylinderWithLowestLoad()
    active_cylinder = urgent_cylinder # Force switch to urgent
else:
    # BALANCED: Alternating logic
    if TimeSinceLastSwitch > BalanceInterval:
        active_cylinder = Toggle(active_cylinder)
        ResetSwitchTimer()
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

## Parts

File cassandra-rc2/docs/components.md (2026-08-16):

# Component System Documentation

This document describes the component-based architecture used in the firmware.

## Overview

The firmware utilizes a modular design where different functionalities (hardware interfaces, communication managers, etc.) are implemented as separate "Components". This promotes code reusability, organization, and easier maintenance.

## Core Concepts

1.  **`Component` Base Class (`src/Component.h`):**
    *   All functional units inherit from the base `Component` class.
    *   Provides common properties like `name`, `id` (unique identifier from `COMPONENT_KEY` enum in `src/enums.h`), `owner` (pointer to the parent component, usually `PHApp`), `flags` (for controlling behavior like setup/loop execution), and `nFlags` (for network capabilities).
    *   Defines standard virtual methods that can be overridden by derived classes:
        *   `setup()`: Called once during application initialization.
        *   `loop()`: Called repeatedly in the main application loop.
        *   `info()`: Used for printing component status/information (often called via serial command).
        *   `debug()`: Used for printing debugging information.
        *   `onRegisterMethods(Bridge* bridge)`: Used to register methods that can be called via the `Bridge` (e.g., through serial commands).
        *   `readNetworkValue(short address)` / `writeNetworkValue(short address, short value)`: Interface for network managers (like `ModbusManager`) to interact with the component's data.
        *   `notifyStateChange()`: Intended to be called by components when their state changes, although currently not actively used by managers.

2.  **`App` / `PHApp` (`src/App.h`, `src/PHApp.h`):**
    *   `App` is the base application class, inheriting from `Component`.
    *   `PHApp` is the specific application implementation for this project.
    *   `PHApp` acts as the central orchestrator and owner of most components.
    *   It maintains a `Vector<Component*> components` list to hold pointers to all active components.
    *   **Initialization (`PHApp::setup()`):**
        *   Instantiates necessary components (like `Bridge`, `SerialMessage`, `ModbusManager`, `Relay`, etc.).
        *   Adds component pointers to the `components` vector using `components.push_back()`. **Crucially, `components.setStorage(componentsArray);` must be called in the `App` constructor (`App.cpp`) for the vector to function correctly.**
        *   Calls `App::setup()`, which iterates through the `components` vector and calls the `setup()` method of each component (if the `E_OF_SETUP` flag is set).
        *   Registers components with managers (e.g., `modbusManager->registerComponentAddress(...)`).
        *   Registers component methods with the `Bridge` (`registerComponents(bridge)`).
    *   **Main Loop (`PHApp::loop()`):**
        *   Calls `App::loop()`, which iterates through the `components` vector and calls the `loop()` method of each component (if the `E_OF_LOOP` flag is set).

3.  **Configuration (`src/config.h`, `src/features.h`, `src/config_secrets.h`, `src/config-modbus.h`):**
    *   Hardware pin assignments (e.g., `MB_RELAY_0`, `STATUS_WARNING_PIN`) are typically defined in `config.h`.
    *   Feature flags (e.g., `ENABLE_MODBUS_TCP`, `HAS_STATUS`) used for conditional compilation are often in `features.h` or `config_adv.h`.
    *   Sensitive information like WiFi credentials should be in `config_secrets.h` (which should not be committed to version control).
    *   Modbus addresses are centralized in `config-modbus.h`.
    *   Component IDs are defined in `src/enums.h`.

## Adding a New Component

Let's illustrate with a hypothetical example: adding a simple Temperature Sensor component.

1.  **Define Configuration:**
    *   Add pin definition to `config.h`: `#define TEMP_SENSOR_PIN 34`
    *   Add component ID to `enums.h` (`COMPONENT_KEY` enum): `COMPONENT_KEY_TEMP_SENSOR_0 = 800,`
    *   (Optional) Add Modbus address to `config-modbus.h`: `#define MB_IREG_TEMP_SENSOR_0 800`
    *   (Optional) Add feature flag to `features.h`: `#define HAS_TEMP_SENSOR_0`

2.  **Create Component Class (`src/TempSensor.h`):**
    ```cpp
    #ifndef TEMP_SENSOR_H
    #define TEMP_SENSOR_H

    #include "Component.h"
    #include "enums.h"
    #include <ArduinoLog.h>
    // Include any specific sensor libraries if needed

    class Bridge;

    class TempSensor : public Component {
    private:
        const short pin;
        float currentValue;
        short modbusAddress;

    public:
        TempSensor(Component* owner, short _pin, short _id, short _modbusAddr)
            : Component("TempSensor", _id, COMPONENT_DEFAULT, owner),
              pin(_pin),
              currentValue(0.0),
              modbusAddress(_modbusAddr)
        {
            // Enable Modbus capability if needed
            setNetCapability(OBJECT_NET_CAPS::E_NCAPS_MODBUS);
            // Ensure loop() is called
            // setFlag(OBJECT_RUN_FLAGS::E_OF_LOOP); // Already in COMPONENT_DEFAULT
        }

        short setup() override {
            Component::setup();
            // Initialize sensor library, set pin mode, etc.
            // pinMode(pin, INPUT); // Example
            Log.verboseln("TempSensor::setup - ID: %d, Pin: %d, Modbus Addr: %d", id, pin, modbusAddress);
            return E_OK;
        }

        short loop() override {
            Component::loop();
            // Read sensor value periodically
            // currentValue = analogRead(pin); // Simplified example
            // Add proper timing logic (e.g., read every second)
            return E_OK;
        }

        short info(short arg1 = 0, short arg2 = 0) override {
             Log.verboseln("TempSensor::info - ID: %d, Pin: %d, Value: %F, Modbus Addr: %d", id, pin, currentValue, modbusAddress);
             return E_OK;
        }

        // --- Network Interface ---
        short readNetworkValue(short address) override {
            if (address == modbusAddress) {
                // Convert float to Modbus register format (e.g., integer degrees * 10)
                return (short)(currentValue * 10.0);
            }
            return 0; // Not handled
        }

        // Optional: Implement writeNetworkValue if temperature could be set (e.g., for simulation)
        // virtual short writeNetworkValue(short address, short value) override { ... }

        // Register methods for serial commands
        short onRegisterMethods(Bridge* bridge) override {
             Component::onRegisterMethods(bridge);
             bridge->registerMemberFunction(id, this, C_STR("info"), (ComponentFnPtr)&TempSensor::info);
             // Add other methods if needed
             return E_OK;
        }
    };

    #endif // TEMP_SENSOR_H
    ```

3.  **Instantiate and Register in `PHApp`:**
    *   **`PHApp.h`:**
        *   Include `TempSensor.h` (likely within `#ifdef HAS_TEMP_SENSOR_0`).
        *   Declare a pointer: `TempSensor* tempSensor_0;`.
    *   **`PHApp.cpp` (`PHApp::setup()`):**
        ```cpp
        // ... other includes ...
        #ifdef HAS_TEMP_SENSOR_0
        #include "TempSensor.h"
        #endif

        // ... inside PHApp::setup() ...

        #ifdef HAS_TEMP_SENSOR_0
        tempSensor_0 = new TempSensor(this,
                                      TEMP_SENSOR_PIN,
                                      COMPONENT_KEY_TEMP_SENSOR_0,
                                      MB_IREG_TEMP_SENSOR_0);
        components.push_back(tempSensor_0);
        #else
        tempSensor_0 = nullptr;
        #endif

        // ... later, after App::setup() ...

        // --- Register Components with Modbus Manager ---
        #if defined(ENABLE_MODBUS_TCP)
        if (modbusManager) {
            // ... other registrations ...
            #ifdef HAS_TEMP_SENSOR_0
            if (tempSensor_0) modbusManager->registerComponentAddress(tempSensor_0, MB_IREG_TEMP_SENSOR_0, 1);
            #endif
        }
        #endif

        // ... registerComponents(bridge) will handle calling TempSensor::onRegisterMethods ...
        ```

4.  **Build and Test:** Recompile (`npm run build`), upload (`npm run upload`), and test using serial commands (`npm run send -- "<<800;2;64;info:0:0>>"`) and Modbus tools (`python scripts/modbus_read_registers.py --address 800 --ip-address <IP>`).

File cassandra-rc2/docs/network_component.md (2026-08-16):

# NetworkComponent Architecture

## 1. Overview

The `NetworkComponent` class serves as a generic, network-aware base class for components that need to expose values over Modbus and other network protocols. It is designed to reduce boilerplate by providing default implementations for common network-related tasks, including Modbus registration, message handling, and a standardized enable/disable mechanism.

## 2. Core Features

### a. Default "Enabled" Coil

By default, every `NetworkComponent` automatically registers a `NetworkValue<bool>` named `m_enabled`.

-   **Modbus Address**: This coil is always located at `mb_tcp_base_address() + 0`.
-   **Functionality**: Writing to this coil via Modbus will enable or disable the component's main loop logic by setting the component's internal `E_OF_DISABLED` flag. This provides a standardized way to remotely control component activity.

### b. `loopNetwork()` Method

Derived components should place their primary operational logic inside the `loopNetwork()` method, not the standard `loop()` method.

The base `NetworkComponent::loop()` method will first check the state of the `m_enabled` coil. If the component is disabled, the `loop()` method will exit early, preventing `loopNetwork()` from being called. This ensures that the enabled state is always respected.

### c. Centralized Network Methods

`NetworkComponent` provides default implementations for several key virtual methods from the `Component` base class:

-   `mb_tcp_register()`: Automatically iterates through the component's registered Modbus blocks and registers them with the `ModbusTCP` manager.
-   `mb_tcp_blocks()`: Returns the view of the component's Modbus blocks.
-   `mb_tcp_read()` / `mb_tcp_write()`: Automatically handle read/write requests for the default `m_enabled` coil.
-   `onMessage()`: Provides a default handler that forwards Protobuf messages (`EC_PROTOBUF_UPDATE`) to the component's owner, which is typically the `RestServer` for broadcasting.

Derived classes should not need to override these methods unless they need to add new behavior.

## 3. Required Implementation by Subclasses

To use `NetworkComponent`, a derived class **must** implement the following:

-   A constructor that calls the `NetworkComponent` base constructor.
-   `uint16_t mb_tcp_base_address() const override`: Must return the unique starting Modbus address for this component instance.
-   `setup()`: Must call `NetworkComponent::setup()` and then register its own `NetworkValue` instances and Modbus blocks.
-   `loopNetwork()`: Contains the component's primary operational logic.
-   `mb_tcp_read(MB_Registers* reg) override`: Must first call `on_mb_tcp_read(reg, &value)`. If this returns `true`, the value has been handled by the base class. Otherwise, the method should handle its own registers.
-   `mb_tcp_write(MB_Registers* reg, short value) override`: Must first call `on_mb_tcp_write(reg, value)`. If this returns `true`, the request has been handled. Otherwise, the method should handle its own registers.

This architecture ensures that components are lean and focused on their specific logic, while the `NetworkComponent` base class handles the common, error-prone networking boilerplate.

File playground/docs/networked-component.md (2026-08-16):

## Network-enabled Components – Incremental Design Notes

The objective is to remove repetitive boiler-plate around Modbus exposure while staying 100 % compatible with the existing `NetworkValue` feature set and the current component hierarchy.

### 1. Helper mix-in: `ModbusBindable<N>`
* Template parameter **`N`** = compile-time count of Modbus fields a component wants to expose.
* Derives from `Component` (exactly like `ModbusDevice<N>` today) and pre-allocates the `MB_Registers` array plus view.
* Adds two convenience wrappers:
  1. `registerField(id, name, fnCode, access)` – returns reference to the freshly allocated `MB_Registers` entry so the caller can immediately call `.bind(myNetworkValue)`.
  2. `bind(NetworkValue<T>& nv)` – copies the addressing information and keeps a pointer so that later **`enable()`** / **`disable()`** can toggle `NetworkValueFeatureFlags::MODBUS` for the field in one place.

This reduces a typical component constructor to a short chain:
```cpp
using NVf = NetworkValue<int>;
_modbus.registerField(Temperature, "Temp", FN_READ_HOLD_REGISTER, MB_ACCESS_READ_ONLY)
       .bind(_temperatureNV);
```
No manual index math, no local `_modbusBlocks[i] = …`.

### 2. Runtime toggle
Expose two helpers:
```cpp
void Component::enableNet()   { SBI(nFlags, OBJECT_NET_CAPS::E_NCAPS_MODBUS); }
void Component::disableNet()  { CBI(nFlags, OBJECT_NET_CAPS::E_NCAPS_MODBUS); }
```
`ModbusBindable` observes the flag in its `loop()` and calls `.enableFeature(MODBUS)` or `.disableFeature(MODBUS)` on every bound `NetworkValue` once when the state flips.

### 3. Stable logical identifiers
Today the only handle for a field is its **offset / absolute address** and a free-form name. To decouple user-code from register maps introduce:

1. A small `enum class` per component describing its logical fields – e.g. `enum class OmronField : uint8_t { PV, SP, StatusLow, … }`.
2. Each `MB_Registers` gains a new member `uint8_t logicalId` holding the cast value of that enum.
3. Helpers `byId(OmronField f)` and `mb_tcp_write(logicalId, value)` eliminate hard-coded offsets in the business logic.

Address computation stays automatic inside the `registerField()` helper which receives the enum value and returns the concrete startAddress.

### 4. Optional syntactic sugar – field builder
A single-line macro speeds up definition:
```cpp
#define NV_FIELD(enumId, nvRef, fn, acc) \
    registerField(enumId, #enumId, fn, acc).bind(nvRef)
```
Example:
```cpp
NV_FIELD(OmronField::PV,   _pv,  FN_READ_HOLD_REGISTER, MB_ACCESS_READ_ONLY);
NV_FIELD(OmronField::SP,   _sp,  FN_WRITE_HOLD_REGISTER, MB_ACCESS_READ_WRITE);
```

### 5. Migration path
1. Keep `ModbusDevice<N>` working untouched.
2. Introduce `ModbusBindable<N>` side-by-side – early adopters can switch gradually.
3. After all components migrate, retire the older mix-in.

### 6. Minimal runtime footprint
All helpers are `constexpr` / `inline`; no dynamic allocation, no RTTI, no `std` containers – fits ESP32 & PlatformIO constraints.

### 7. Quick architecture overview
```mermaid
graph TD
  Comp("Component") -->|mixin| MB["ModbusBindable<N>"]
  MB --> NV("NetworkValue<T>")
  MB --> Regs["MB_Registers[N]"]
  Comp -- enable/disable --> MB
```

---
**Next step**: draft the actual `ModbusBindable` header and refactor one small component (`NetworkValueTest`) as proof-of-concept.

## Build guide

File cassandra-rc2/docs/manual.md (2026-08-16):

# Manual Mode Refactor Proposal

**Status:** Implemented
**Feature:** Enhanced Manual Mode Safety & Interlock Support

## Problem Statement

Currently, `PressCylinder::onJoystickUp` implements a simplified manual control loop that bypasses safety checks (`CFlags`) and complex logic available in `loopSingle` and `loopMulti`. It directly enables solenoids based on Joystick Position, ignoring:

* Load balancing (in multi-cylinder setups)
* Stall detection
* Interlock status (implicitly, though safety overrides exist)
* Operation timeouts

The goal is to unify the logic so that "Manual" operation is simply a special case of the robust `loop*` functions, but controlled by the Joystick/PushButton rather than a fixed "Auto" process.

## Proposed Strategy

We will treat Manual operation as "Auto operation towards a Virtual Maximum Target" that only persists while the operator holds the input (Joystick or PushButton).

### 1. Unified Control Logic

Instead of direct `SOLENOID_ON/OFF` in `onJoystickUp`, we will:

1. Detect "Active Input" (Joystick UP *OR* PushButton Pressed).
2. If Active:
    * Temporarily override `m_targetSP` to `100%` (or a `manual_override_sp`).
    * Set effective mode to `DEFAULT_AUTO_MODE_NORMAL` (if single/unlocked) or `DEFAULT_AUTO_MODE_INTERLOCKED` (if interlocked).
    * Call `loopSingle()` or `loopMulti()` respectively.
3. If Inactive:
    * Reset `m_targetSP` to 0 (or restore original).
    * Enforce `SOLENOIDS_OFF`.

### 2. Implementation Plan

#### A. Define Helper: `getVirtualTargetSP()`

For manual moves, we want to press as long as the operator commands, up to the absolute hardware limit (`maxload_threshold` or `100%`).

```cpp
uint32_t PressCylinder::getVirtualTargetSP() {
    // In Manual mode, "Target" is effectively "Go until Max or Stop"
    return 70; // 70% of maxload_threshold (Virtual SP Max)
}
```

#### B. Refactor `onJoystickUp` / Main Loop Integration

We will stop using `onJoystickUp` as a direct actuator. Instead, it becomes an input state detector.

**Modified `loop()` Logic:**

```cpp
// 1. Determine "Effective Mode" and "Effective Target"
E_Mode effective_mode = (E_Mode)m_mode.getValue();
uint32_t effective_sp = m_targetSP.getValue();
bool manual_input_active = false;

// Check Inputs (Joystick or PushButton)
    // Check Inputs (Joystick or PushButton)
    if (_pushButton->getState() == PushButton::State::PRESSED || _pushButton->getState() == PushButton::State::HELD) {
        // Condition 1: PushButton Held -> Force Manual Single Cylinder
        manual_input_active = true;
        effective_mode = MODE_MANUAL;
        effective_sp = 70; 
    }
    else if (_joystick->getPosition() == Joystick::E_POSITION::UP) {
        // Condition 2: Joystick UP -> Smart Auto / Interlock Dependent
        manual_input_active = true;
        effective_sp = 70;
        
        if (effective_mode == MODE_MANUAL || effective_mode == MODE_MANUAL_MULTI) {
             if (m_interlocked.getValue()) {
                  effective_mode = DEFAULT_AUTO_MODE_INTERLOCKED; // e.g. AUTO_MULTI_BALANCED
             } else {
                  effective_mode = DEFAULT_AUTO_MODE_NORMAL; // e.g. AUTO
             }
        }
    }

// 2. Dispatch to Control Loops
if (manual_input_active || isAutoRunning()) {
    // These functions now use 'effective_mode' and 'effective_sp' 
    // instead of reading m_targetSP/m_mode directly if we pass them as args,
    // OR we temporarily override member vars (simpler but riskier state).
    
    // BETTER APPROACH: Refactor loopSingle/loopMulti to take args
    if (isMultiMode(effective_mode)) {
        loopMulti(effective_mode, effective_sp);
    } else {
        loopSingle(effective_mode, effective_sp);
    }
} else {
    // Idle / Stop
    SOLENOIDS_OFF();
}
```

### 3. Modifications Required

1. **Refactor `loopSingle` / `loopMulti`**:
    * Change signature to accept `E_Mode mode` and `uint16_t target_sp` arguments.
    * Remove internal calls to `m_mode.getValue()` and `m_targetSP.getValue()` in favor of these arguments.

2. **Update `onJoystickUp`**:
    * Actually, we might deprecate `onJoystickUp` direct logic entirely and move it into the main `loop()` structure as shown above.
    * Retain `onJoystickDoubleUp` for the HOLD feature (capturing Load to SP).

3. **PushButton Integration**:
    * Map `_pushButton->getState() == PushButton::State::PRESSED` (or HELD) to `manual_input_active`.

### 4. Safety Considerations

* **Deadman Switch**: The moment the Joystick/Button is released, `manual_input_active` becomes false, and the `else` block triggers `SOLENOIDS_OFF()`.
* **Existing Safety**: `loopSingle/Multi` already contain `CheckMinLoad`, `Stall`, `Balance`, and `MaxTime` checks. By routing manual control through them, we gain all these features automatically.
* **Virtual SP**: Setting SP to 100% is safe because `loop*` logic checks `canPress()` which respects `maxload_threshold`.

## Diagram: New Flow

```mermaid
graph TD
    Input[Inputs: Joystick / Button] --> Check{Active?}
    Check -- Yes --> MapMode[Map to Effective Auto Mode]
    MapMode --> SetSP[Set Virtual SP = 70%]
    SetSP --> Dispatch{Is Multi?}
    
    Dispatch -- Single --> LoopSingle[loopSingle(SafeMode, 70%)]
    Dispatch -- Multi --> LoopMulti[loopMulti(SafeMode, 70%)]
    
    LoopSingle --> Actuators
    LoopMulti --> Actuators
    
    Check -- No --> Stop[SOLENOIDS_OFF]
```

### References

### Data

cs-1150 - interlocked

min load : 50-150

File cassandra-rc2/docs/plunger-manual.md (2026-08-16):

# Plunger Component - User Manual

This document describes how to operate the Plunger component using the joystick and understand its different modes.

## References

- [Plunger Settings](./plunger-settings.md.md)
- [Elena - RC2 - Official](https://polymech.io/en/store/products/injection/elena-zmax-rc1/)

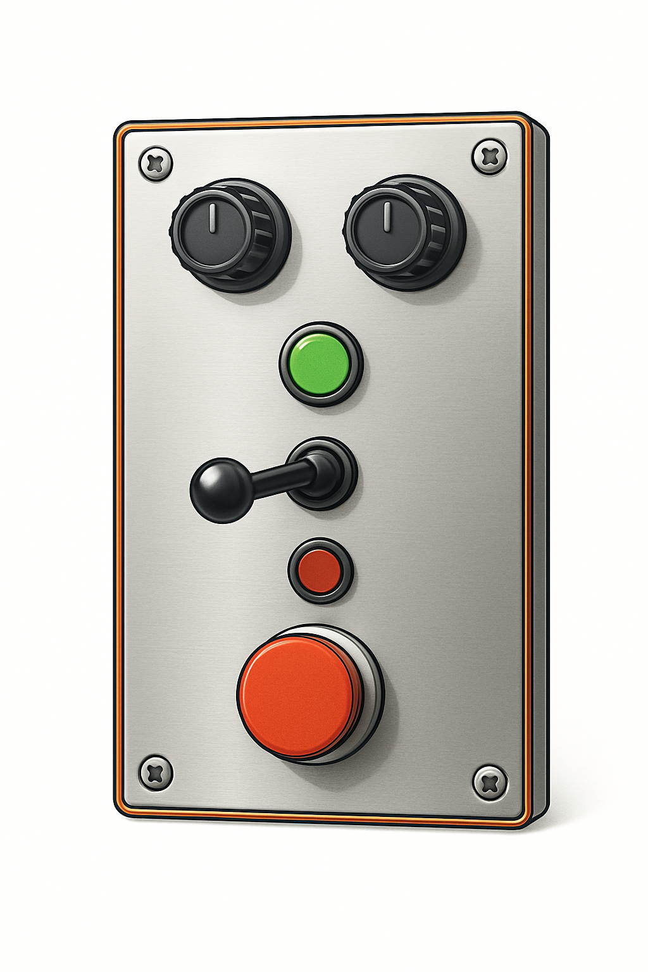
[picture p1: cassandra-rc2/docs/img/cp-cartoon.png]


## Joystick Operations

The joystick controls the primary functions of the plunger. Ensure the system is **not moving and ready for a new command** before initiating most new joystick actions. The Plunger component has an "Auto Mode" which can be enabled or disabled via separate commands (see Advanced Controls). When Auto Mode is enabled, holding the joystick in a direction for an extended period can trigger automatic continuous movement.

**Joystick Directions:**

*   **UP**: Move Plunger UP (Homing/Retracting)
*   **DOWN**: Move Plunger DOWN (Plunging/Extending)
*   **LEFT**: Initiate FILLING sequence
*   **RIGHT**: Initiate RECORD or REPLAY sequence
*   **CENTER**: Stop manual movement / Neutral position

---

### 1. Speed Control Dial (Potentiometer)

The Plunger is equipped with a speed control dial. This dial allows you to adjust the **downward plunging speed**.

*   **Function**: Turning the dial will increase or decrease the speed at which the plunger moves downwards during Manual Plunging, Automatic Plunging, Record mode, Replay mode, and the plunging phase of the Filling sequence.
*   **Note**: The upward homing speed (including during the Filling sequence's homing phase) is generally fixed at a slower, safer speed and is not affected by this dial.

---

### 2. Sensitivity Dial: How Quickly the Plunger Stops

This dial adjusts how sensitive the plunger is when it's moving **DOWN**. This changes how quickly it will stop if it hits something.

*   **What it does**: It tells the plunger how easily it should decide it's "stuck" or has "bumped into something" when moving downwards.

*   **How to use it**:

    *   **Turn for "Quick Stop" (Most Sensitive setting):**
        *   Imagine turning this dial all the way up (e.g., to a number like 100, or a symbol showing a quick stop 🛑).
        *   **Result**: The plunger becomes super alert! It will stop **immediately** the moment it touches anything in its path. It won't push hard; it will just stop right away.
        *   **Use this when**: You want the plunger to be extra careful and stop with just the slightest touch.

    *   **Turn for "Normal Stop" (Least Sensitive setting):**
        *   Imagine turning this dial all the way down (e.g., to a number like 0, or a symbol showing normal work 💪).
        *   **Result**: The plunger will use its normal pushing strength. It will push against things for a moment before deciding to stop. It won't stop for tiny, light bumps that it might otherwise push through.
        *   **Use this when**: It's okay for the plunger to push a bit to do its job, and you don't want it to stop for every tiny thing.

    *   **In-between settings**: You can choose a setting in the middle to get a balance that's just right for your task!

*   **Important**: This dial mostly changes how the plunger reacts when it's moving **DOWN** (plunging). It doesn't change how it moves when going up.

---

### 3. Manual Plunging (Moving Down)

*   **Action**: Push the joystick **DOWN**.
*   **Result**: The plunger will start moving downwards. The speed is determined by the **Speed Control Dial**.
    *   To continue moving manually, keep the joystick held DOWN.
    *   To stop manual movement, release the joystick to the **CENTER** position. The plunger will stop.
*   **Automatic Plunging (if "Auto Mode" is enabled)**:
    *   If you **continue to hold** the joystick **DOWN** for more than **3.5 seconds**, the plunger will switch to **Automatic Plunging** mode.
    *   Once in Automatic Plunging, you can release the joystick to the CENTER position, and the plunger will continue moving down at the speed set by the Speed Control Dial.
    *   **To stop Automatic Plunging**: Move the joystick to any other position (e.g., UP, LEFT, RIGHT, or briefly back to DOWN then CENTER). The plunger will stop.

### 4. Manual Homing (Moving Up)

*   **Action**: Push the joystick **UP**.
*   **Result**: The plunger will start moving upwards at a fixed slow speed.
    *   To continue moving manually, keep the joystick held UP.
    *   To stop manual movement, release the joystick to the **CENTER** position. The plunger will stop.
*   **Automatic Homing (if "Auto Mode" is enabled)**:
    *   If you **continue to hold** the joystick **UP** for more than **3.5 seconds**, the plunger will switch to **Automatic Homing** mode.
    *   Once in Automatic Homing, you can release the joystick to the CENTER position, and the plunger will continue moving up.
    *   **To stop Automatic Homing**: Move the joystick to any other position. The plunger will stop.

---

### 5. Filling Sequence

The filling sequence is an automated process: the plunger moves down until it senses the container is full (by detecting a jam), waits a moment, moves all the way up until it reaches the top (another jam), waits again, and then is ready for the next action.

The plunging (downward) speed during this sequence is affected by the Speed Control Dial. The upward (homing) speed is a fixed slow speed.

*   **Action**: When the plunger is **not moving and ready**, push and **HOLD** the joystick to the **LEFT** for at least **2.5 seconds**.
*   **Result - The Automated Sequence**:
    1.  The plunger will start moving **DOWN**.
    2.  When the plunger detects that the container is full (it senses a jam/resistance), it will automatically stop.
    3.  It will then **wait** in place for **1.3 seconds**.
    4.  After this short wait, it will automatically start moving **UP**.
    5.  When the plunger reaches its topmost position (it senses a jam/resistance at the top), it will automatically stop.
    6.  It will then **wait** in this top position for **1.5 seconds**.
    7.  After this final wait, the filling sequence is complete, and the plunger will be **ready for a new command**.
*   **To Abort Filling Sequence**: Once the filling sequence has started (after you've held the joystick left and then released it to the center), if you move the joystick in **ANY direction** away from the CENTER position, the entire filling sequence will be cancelled. The plunger will stop and become **ready for a new command**.

---

### 6. Record & Replay Plunge Duration

This feature allows you to record a specific plunging duration and then replay it. The plunging speed during record and replay is affected by the Speed Control Dial.

#### 6.1. Record Plunge Duration

*   **Action**: When the plunger is **not moving and ready**, push and **HOLD** the joystick to the **RIGHT** for at least **3 seconds**.
*   **Result**:
    1.  The plunger enters **Record Mode** and starts moving **DOWN** at the speed set by the dial.
    2.  Keep holding the joystick RIGHT for the desired duration of the plunge.
    3.  **Release the joystick** (to CENTER or any other direction) when you want to stop recording the plunge.
    4.  The duration of this plunge is now recorded. The plunger stops and is **ready for a new command**.
*   **Maximum Record Time**: The recording will automatically stop if it exceeds **20 seconds**.

#### 6.2. Replay Recorded Plunge

*   **Action**: When the plunger is **not moving and ready**, briefly **TAP** the joystick to the **RIGHT** (push and release quickly, holding for less than 3 seconds).
*   **Result**:
    1.  If a plunge duration has been previously recorded (or set via settings), the plunger enters **Replay Mode**.
    2.  It will automatically plunge **DOWN** for the recorded duration, at the speed set by the dial.
    3.  After the duration, it will stop and become **ready for a new command**.
    4.  The default replay duration if no recording has been made or loaded from settings is **4.5 seconds**.
*   **To Abort Replay**: During replay, moving the joystick in **ANY direction** away from CENTER will stop the replay, and the plunger will become **ready for a new command**.
*   **No Recording**: If you tap RIGHT and no duration has been recorded or set, nothing will happen.

---

### 7. Jammed State and Resetting

*   **Indication**: If the plunger encounters excessive resistance during any movement (manual, auto, fill, record, replay), it will become **jammed**, and the motor will stop.
*   **To Reset from a Jam**:
    1.  Ensure the joystick is in the **CENTER** position. The system is now attempting to clear the jam.
    2.  From this state, push the joystick **UP**. This will try to fully reset the VFD fault and start moving the plunger upwards manually.
    3.  If you move the joystick to any other direction (not UP) while it's attempting to clear a jam (after first centering it), it will also try to reset the VFD fault and then become **ready for a new command**. A manual VFD reset by a technician might sometimes be needed if this occurs and the VFD remains unresponsive.

---
## Notes

*   The exact timings mentioned are based on current default settings but **can be configured** via a settings file (see Advanced Controls section if available).
*   Adjust the **Speed Control Dial** to change the downward plunging speed for most operations.
*   Always ensure the area around the plunger is clear before operation.
*   Pay attention to system warnings or error messages if the plunger behaves unexpectedly. 
*   

## Web Interface

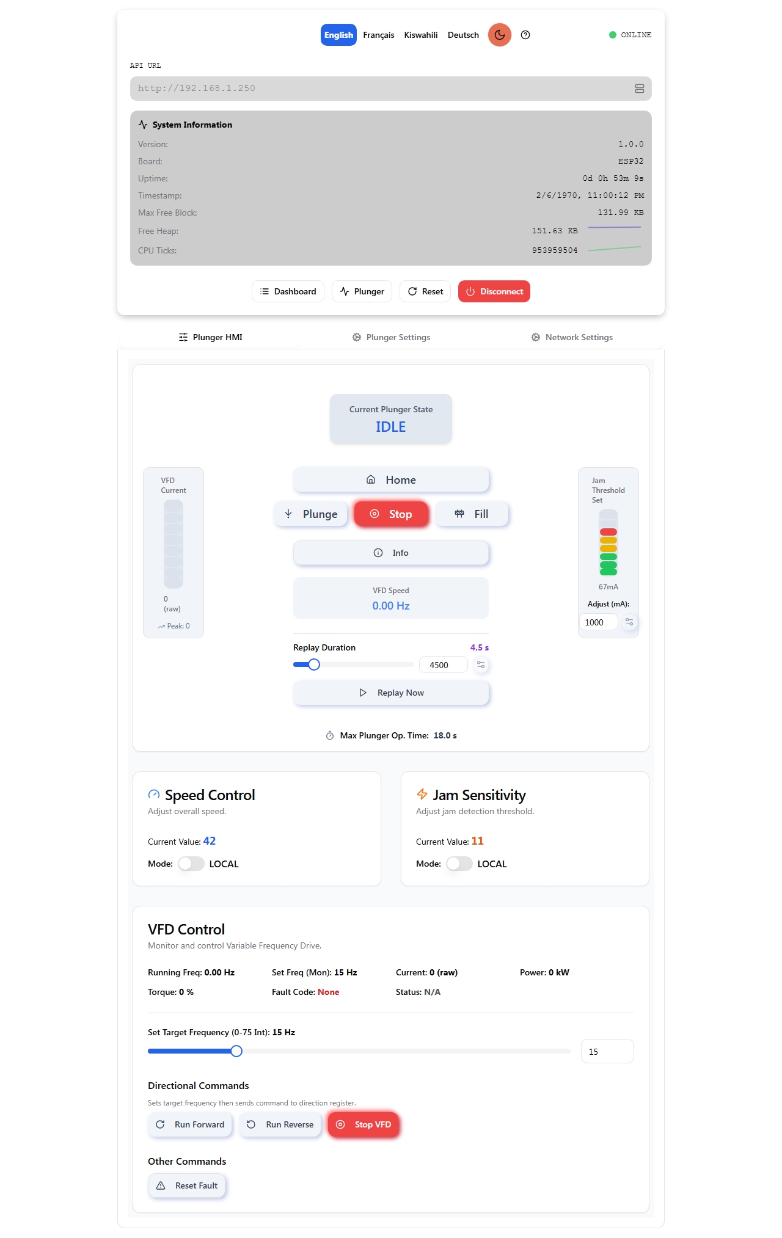
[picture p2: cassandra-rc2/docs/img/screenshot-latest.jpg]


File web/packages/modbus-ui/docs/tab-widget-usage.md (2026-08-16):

# Tab Widget Usage

The Tab Widget provides a tabbed interface with individual layout containers for each tab, similar to the AdvancedPage implementation but as a reusable widget.

## Features

- **Dynamic Tab Management**: Add/remove tabs with a plus button
- **Nested Routing**: Each tab creates its own route under the current URL
- **Individual Layout Containers**: Each tab has its own layout area for widgets
- **Persistent State**: Tab configuration and last active tab are saved to localStorage
- **Edit Mode**: Double-click tab labels to rename them
- **Configurable**: Maximum tabs, default columns, and other settings

## Usage in Routes

The TabWidget integrates with React Router and creates nested routes:

```
/your-page/
├── tab1 (first tab)
├── tab2 (second tab)
└── custom-tab-name (additional tabs)
```

## Widget Properties

- `widgetId`: Unique identifier for the widget instance (default: 'tab-widget')
- `initialTabs`: Array of initial tab configurations
- `maxTabs`: Maximum number of tabs allowed (default: 10)
- `defaultColumns`: Default number of columns in each tab's layout (default: 2)
- `showTitle`: Whether to show container titles (default: false)

## Tab Configuration

Each tab has:
- `id`: Unique identifier
- `label`: Display name (editable by double-clicking)
- `route`: URL route segment

## Layout Integration

Each tab contains a layout container that:
- Supports adding/removing widgets in edit mode
- Has configurable column layout
- Persists widget arrangement
- Integrates with the existing widget system

## Example Usage

The widget is registered in the widget registry and can be added to any layout container through the widget palette.

## Technical Implementation

- **TabWidget**: Main component handling tab navigation and management
- **TabContent**: Layout container for each tab's content
- **TabWidgetContainer**: Wrapper component that sets up routing
- Uses React Router's nested routing with `<Outlet>` for tab content
- Leverages existing LayoutContext for widget management
- Follows the same patterns as AdvancedPage for consistency

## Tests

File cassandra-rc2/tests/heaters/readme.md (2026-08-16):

# Heater Tests

## Triangle - Test - A1 - 1150 (7:40) - 400V / 300 W

- **Block Size** : 120x80x20 mm
- **Heater Size** : 11.35 mm
- **Groove Size** : 11.7 mm Nominal | 11.45 mm slide fit
- **T DT - 30 mins** : 80 degc
- **Cell Size** : 250 mm

## Triangle - Test - A1 - 650 (8:30) - 220V / 250W

- **Block Size** : 80x60x20 mm
- **Heater Size** : 11.45 mm
- **Groove Size** : 11.7 mm Nominal | 11.45 mm slide fit
- **T DT - 30 mins** : 80 degc
- **Cell Size** : 220 mm

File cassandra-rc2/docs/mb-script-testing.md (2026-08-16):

# Modbus Logic Engine (MB_SCRIPT) Functional Testing Strategy

## 1. Objective

To verify the functional correctness of the `ModbusLogicEngine` component (enabled by the `ENABLE_MB_SCRIPT` define). This includes:
*   Correct configuration of logic rules via Modbus.
*   Accurate evaluation of rule conditions based on Modbus register/coil values.
*   Proper execution of defined actions (writing registers/coils, calling component methods).
*   Correct reporting of rule status, trigger timestamps, and trigger counts via Modbus.
*   Handling of various error conditions.

## 2. Scope

This strategy focuses on black-box functional testing from the perspective of a Modbus client interacting with the device. It does not cover unit testing of individual `ModbusLogicEngine` methods or performance/stress testing (which may have separate test plans).

## 3. Approach

Testing will primarily utilize the existing `npm` scripts which wrap Python helper scripts to interact with the device over Modbus TCP.

*   **Configuration:** Rules will be configured by writing to the specific Modbus holding registers allocated to the Logic Engine (`MODBUS_LOGIC_RULES_START` and subsequent offsets defined in `src/ModbusLogicEngine.h`).
*   **Triggering:** Rule conditions will be triggered by writing appropriate values to the source Modbus holding registers or coils specified in the rule's condition.
*   **Verification:**
    *   Action outcomes will be verified by reading the target Modbus holding registers or coils.
    *   Rule status, timestamps, and trigger counts will be verified by reading the corresponding status registers for the rule.
    *   Internal behavior and potential errors can be monitored using device logs (`npm run build:monitor` or `npm run debug:serial`).
*   **No New Scripts:** This strategy aims to use only the pre-existing `npm` scripts for Modbus interaction.

## 4. Tools

*   **Modbus Read/Write:**
    *   `npm run modbus:read:holding -- --address <addr>`
    *   `npm run modbus:write:holding -- --address <addr> --value <val>`
    *   `npm run modbus:read:coil -- --address <addr>`
    *   `npm run modbus:write:coil -- --address <addr> --value <0|1>`
*   **Logging:**
    *   `npm run build:monitor` (Live serial monitoring)
    *   `npm run debug:serial` (Fetch buffered logs via REST API)
*   **Reference:**
    *   `src/ModbusLogicEngine.h` (for register offsets, enums)
    *   `src/config-modbus.h` (for `MODBUS_LOGIC_RULES_START` address)

## 5. Prerequisites

*   Firmware compiled with `#define ENABLE_MB_SCRIPT` in `config.h` and flashed to the ESP32.
*   Device connected to the network and accessible via its IP address or mDNS name (`modbus-esp32.local` by default).
*   Python environment configured correctly to run the scripts in the `scripts/` directory.
*   Knowledge of the Modbus register mapping for the Logic Engine (starting address + offsets).

## 6. Test Cases

Let `RULE_START = MODBUS_LOGIC_RULES_START`.
Let `RULE_0_BASE = RULE_START`.
Let `RULE_1_BASE = RULE_START + LOGIC_ENGINE_REGISTERS_PER_RULE`.
Offsets are defined in `ModbusLogicEngineOffsets`.

*(Note: Choose suitable, otherwise unused Modbus addresses for source/target registers/coils for testing)*

**TC 1: Basic Rule - Write Holding Register**
1.  **Configure:**
    *   Write `1` to `RULE_0_BASE + ENABLED`.
    *   Write `3` (REG_HOLDING) to `RULE_0_BASE + COND_SRC_TYPE`.
    *   Write `2000` to `RULE_0_BASE + COND_SRC_ADDR`.
    *   Write `0` (EQUAL) to `RULE_0_BASE + COND_OPERATOR`.
    *   Write `123` to `RULE_0_BASE + COND_VALUE`.
    *   Write `3` (WRITE_HOLDING_REGISTER) to `RULE_0_BASE + COMMAND_TYPE`.
    *   Write `2001` to `RULE_0_BASE + COMMAND_TARGET`.
    *   Write `456` to `RULE_0_BASE + COMMAND_PARAM1` (Value to write).
    *   Write `0` to `RULE_0_BASE + COMMAND_PARAM2` (Unused).
    *   Write `0` to `RULE_0_BASE + FLAGS`.
2.  **Trigger:** Write `123` to Modbus address `2000`.
3.  **Verify:**
    *   Read address `2001`. Expected: `456`.
    *   Read `RULE_0_BASE + LAST_STATUS`. Expected: `0` (MB_Error::Success).
    *   Read `RULE_0_BASE + TRIGGER_COUNT`. Expected: `1`.

**TC 2: Condition Operator - Not Equal**
1.  **Configure:** Similar to TC 1, but:
    *   Write `1` (NOT_EQUAL) to `RULE_0_BASE + COND_OPERATOR`.
    *   Write `123` to `RULE_0_BASE + COND_VALUE`.
2.  **Trigger 1:** Write `123` to address `2000`.
3.  **Verify 1:** Read address `2001`. Expected: *Unchanged* from previous state (action should *not* run).
4.  **Trigger 2:** Write `124` to address `2000`.
5.  **Verify 2:**
    *   Read address `2001`. Expected: `456`.
    *   Read `RULE_0_BASE + LAST_STATUS`. Expected: `0` (MB_Error::Success).
    *   Read `RULE_0_BASE + TRIGGER_COUNT`. Expected: Incremented.
    *   *(Repeat for other operators: `<`, `<=`, `>`, `>=`)*

**TC 3: Source Type - Coil**
1.  **Configure:** Similar to TC 1, but:
    *   Write `2` (REG_COIL) to `RULE_0_BASE + COND_SRC_TYPE`.
    *   Write `100` (Test Coil Addr) to `RULE_0_BASE + COND_SRC_ADDR`.
    *   Write `1` to `RULE_0_BASE + COND_VALUE` (Condition is Coil ON).
2.  **Trigger:** Write `1` to Coil address `100`.
3.  **Verify:**
    *   Read address `2001`. Expected: `456`.
    *   Read `RULE_0_BASE + LAST_STATUS`. Expected: `0` (MB_Error::Success).

**TC 4: Action Type - Write Coil**
1.  **Configure:** Similar to TC 1, but:
    *   Write `2` (WRITE_COIL) to `RULE_0_BASE + COMMAND_TYPE`.
    *   Write `101` to `RULE_0_BASE + COMMAND_TARGET`.
    *   Write `1` to `RULE_0_BASE + COMMAND_PARAM1` (Value: ON).
    *   Write `0` to `RULE_0_BASE + COMMAND_PARAM2` (Unused).
2.  **Trigger:** Write `123` to address `2000`.
3.  **Verify:**
    *   Read Coil address `101`. Expected: `1`.
    *   Read `RULE_0_BASE + LAST_STATUS`. Expected: `0` (MB_Error::Success).

**TC 5: Action Type - Call Component Method (Requires Setup)**
*   **Prerequisite:** A method must be registered with the `ModbusLogicEngine` that has a verifiable side-effect readable via Modbus. Example: A simple method in `PHApp` that increments a counter stored in a Modbus register (`e.g., address 3000`).
    ```cpp
    // In PHApp.h (or a test component)
    short testMethod(short p1, short p2) {
        testMethodCounter += p1; // Use p1 (arg1 from rule)
        Log.infoln("Test Method Called! Arg1=%d, Counter: %d", p1, testMethodCounter);
        return E_OK;
    }
    uint16_t testMethodCounter = 0;

    // In PHApp::setup() or where ModbusLogicEngine is initialized
    logicEngine->registerMethod(this->id, 1, // Use app ID and method ID 1
        std::bind(&PHApp::testMethod, this, std::placeholders::_1, std::placeholders::_2));

    // In PHApp::readNetworkValue()
    if (address == 3000) return testMethodCounter;
    ```
1.  **Configure:** Similar to TC 1, but:
    *   Write `100` (CALL_COMPONENT_METHOD) to `RULE_0_BASE + COMMAND_TYPE`.
    *   Write `app->id` to `RULE_0_BASE + COMMAND_TARGET` (Component ID).
    *   Write `1` to `RULE_0_BASE + COMMAND_PARAM1` (Method ID).
    *   Write `5` to `RULE_0_BASE + COMMAND_PARAM2` (Argument 1).
2.  **Initial Read:** Read address `3000`. Note the value (e.g., `X`).
3.  **Trigger:** Write `123` to address `2000`.
4.  **Verify:**
    *   Read address `3000`. Expected: `X + 5`.
    *   Read `RULE_0_BASE + LAST_STATUS`. Expected: `0` (MB_Error::Success).
    *   Check logs (`build:monitor`) for "Test Method Called! Arg1=5".

**TC 6: Rule Enable/Disable**
1.  **Configure:** Configure rule as in TC 1.
2.  **Disable:** Write `0` to `RULE_0_BASE + ENABLED`.
3.  **Trigger:** Write `123` to address `2000`.
4.  **Verify (Disabled):** Read address `2001`. Expected: *Unchanged*. Trigger count should *not* increment.
5.  **Enable:** Write `1` to `RULE_0_BASE + ENABLED`.
6.  **Trigger:** Write `123` to address `2000`.
7.  **Verify (Enabled):** Read address `2001`. Expected: `456`. Trigger count *should* increment.

**TC 7: Error - Invalid Condition Source Address**
1.  **Configure:** Similar to TC 1, but:
    *   Write `9999` (Invalid/Unregistered address) to `RULE_0_BASE + COND_SRC_ADDR`.
2.  **Trigger:** Let the engine loop run.
3.  **Verify:** Read `RULE_0_BASE + LAST_STATUS`. Expected: `2` (MB_Error::IllegalDataAddress).

**TC 8: Error - Invalid Action Target Address (Write)**
1.  **Configure:** Similar to TC 1, but:
    *   Write `9998` (Invalid/Unregistered address) to `RULE_0_BASE + COMMAND_TARGET`.
2.  **Trigger:** Write `123` to address `2000`.
3.  **Verify:** Read `RULE_0_BASE + LAST_STATUS`. Expected: `4` (MB_Error::ServerDeviceFailure).

**TC 9: Error - Invalid Action Target Method (Call)**
1.  **Configure:** Similar to TC 5, but:
    *   Write `99` (Non-existent Method ID) to `RULE_0_BASE + COMMAND_PARAM1`.
2.  **Trigger:** Write `123` to address `2000`.
3.  **Verify:** Read `RULE_0_BASE + LAST_STATUS`. Expected: `2` (MB_Error::IllegalDataAddress).

**TC 10: Status/Counter Reset**
1.  **Configure & Trigger:** Perform TC 1.
2.  **Verify Count:** Read `RULE_0_BASE + TRIGGER_COUNT`. Expected: `1` (or current count).
3.  **Reset Counter:** Write `0` to `RULE_0_BASE + TRIGGER_COUNT`.
4.  **Verify Reset:** Read `RULE_0_BASE + TRIGGER_COUNT`. Expected: `0`.
5.  **Trigger Again:** Write `123` to address `2000`.
6.  **Verify Increment:** Read `RULE_0_BASE + TRIGGER_COUNT`. Expected: `1`.

**TC 11: Debug Flag**
1.  **Configure:** Configure as in TC 1, but:
    *   Write `RULE_FLAG_DEBUG` (value 1) to `RULE_0_BASE + FLAGS`.
2.  **Trigger:** Write `123` to address `2000`.
3.  **Verify:**
    *   Check logs (`build:monitor`). Expected: Verbose logs like "MLE Eval [0]: ...", "MLE Action [0]: ...".
    *   Read address `2001`. Expected: `456`.

**TC 12: Receipt Flag**
1.  **Configure:** Configure as in TC 1, but:
    *   Write `RULE_FLAG_RECEIPT` (value 2) to `RULE_0_BASE + FLAGS`.
2.  **Trigger:** Write `123` to address `2000`.
3.  **Verify:**
    *   Check logs (`build:monitor`). Expected: Info log "MLE: Rule 0 action successful.".
    *   Read address `2001`. Expected: `456`.

**TC 13: Debug + Receipt Flags**
1.  **Configure:** Configure as in TC 1, but:
    *   Write `RULE_FLAG_DEBUG | RULE_FLAG_RECEIPT` (value 3) to `RULE_0_BASE + FLAGS`.
2.  **Trigger:** Write `123` to address `2000`.
3.  **Verify:**
    *   Check logs (`build:monitor`). Expected: Both verbose debug logs and the receipt log.
    *   Read address `2001`. Expected: `456`.

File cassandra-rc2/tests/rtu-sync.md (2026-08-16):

INFO: RTU_Base::setOutputRegisterValue(slaveId: 13, address: 0x2601, value: 30)
INFO: RTU_Base::triggerRTUWrite(slaveId: 13)
INFO: RTU_Base::write(slaveId: 13) - Iterating 2 output registers.
INFO: [OmronE5[13]:633] RTU_Base::write(slaveId: 13) - Processing register index 0: address 0x2601, value 30
INFO: RegisterState::writeToDevice(slaveId: 13, address: 0x2601, value: 30, force: false)
INFO: [ModbusRTU:100] ModbusRTU::writeRegister(slaveId: 13, address: 0x2601, value: 30, force: false)
INFO: [ModbusRTU:100] ModbusRTU::writeRegister - Value has changed or force=true. Queuing write.
INFO: [OmronE5[13]:633] RTU_ index 1: address 0x0000, value 0
INFO: RegisterState::writeToDevice(slaveId: 13, address: 0x0000, value: 0, force: true)
INFO: [ModbusRTU:100] ModbusRTU::writeRegister(slaveId: 13, address: 0x0000, value: 0, force: true)
INFO: [ModbusRTU:100] ModbusRTU::wforce=true. Queuing write.

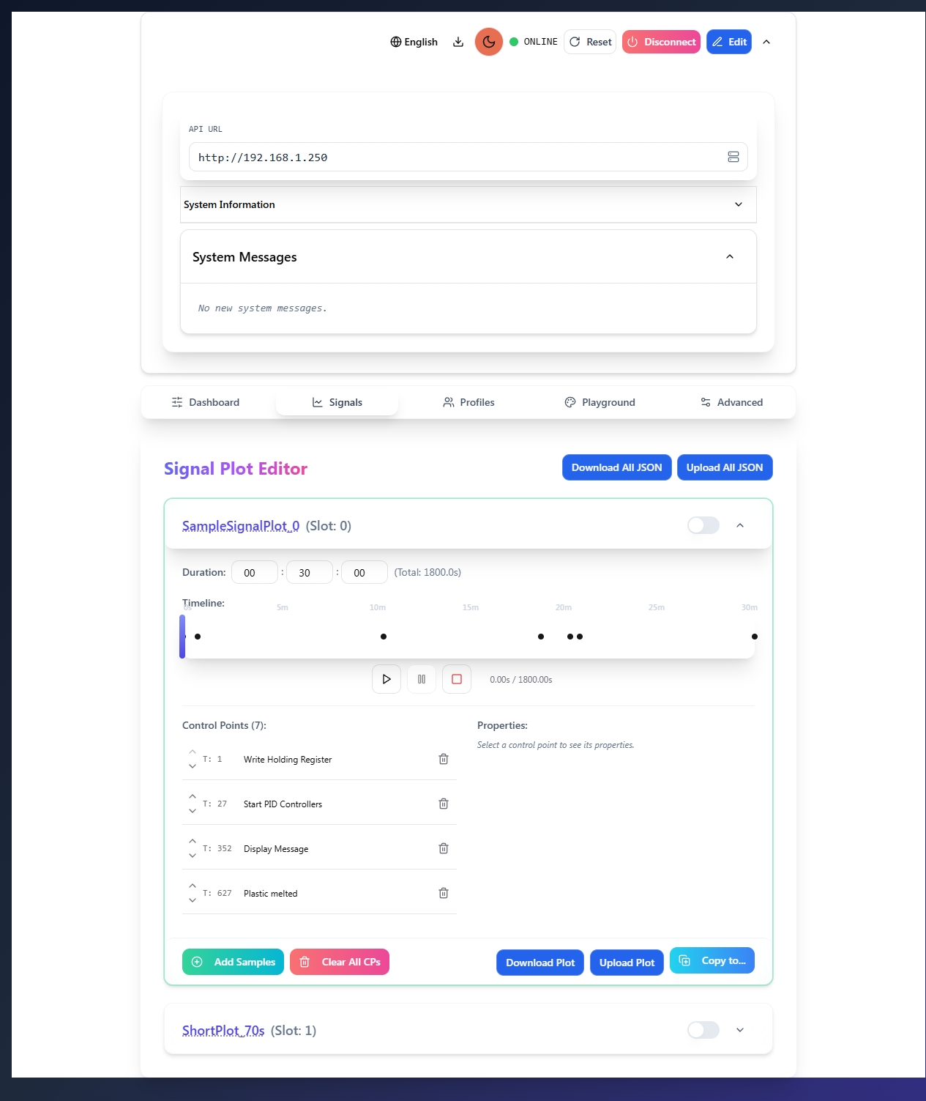
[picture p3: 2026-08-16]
web/packages/modbus-ui/tests/screenshot-signals.jpg

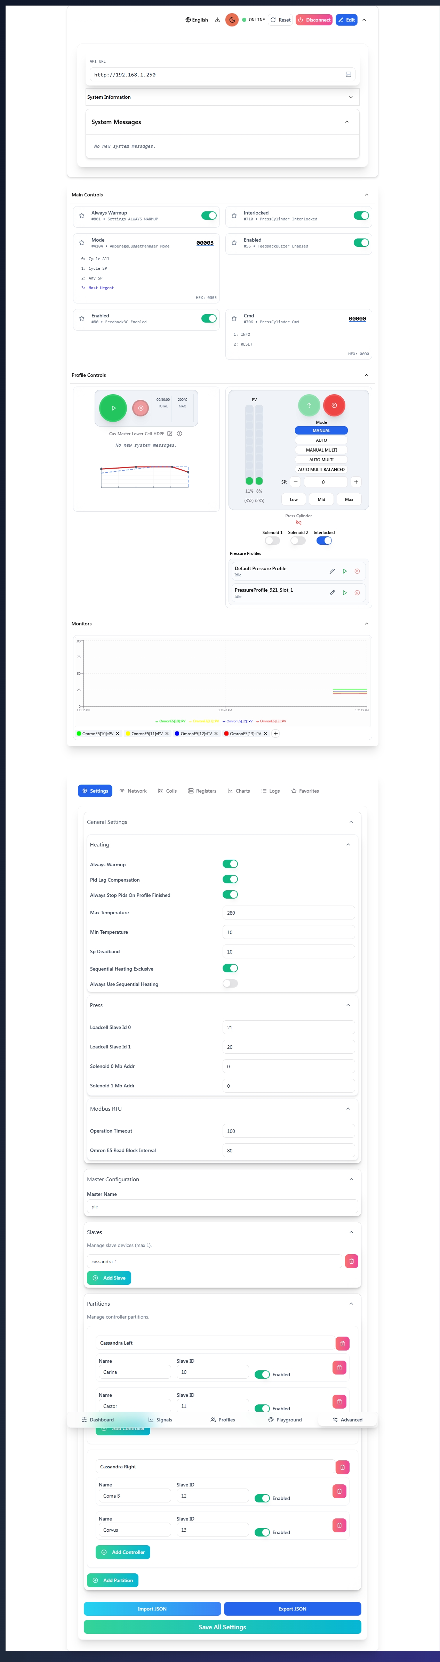
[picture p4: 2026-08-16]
web/packages/modbus-ui/tests/screenshot-advancedsettings.jpg

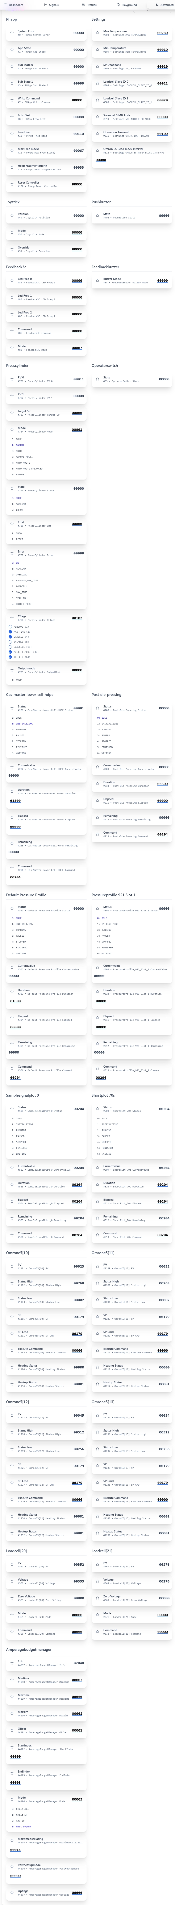
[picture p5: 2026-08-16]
web/packages/modbus-ui/tests/screenshot-registers.jpg

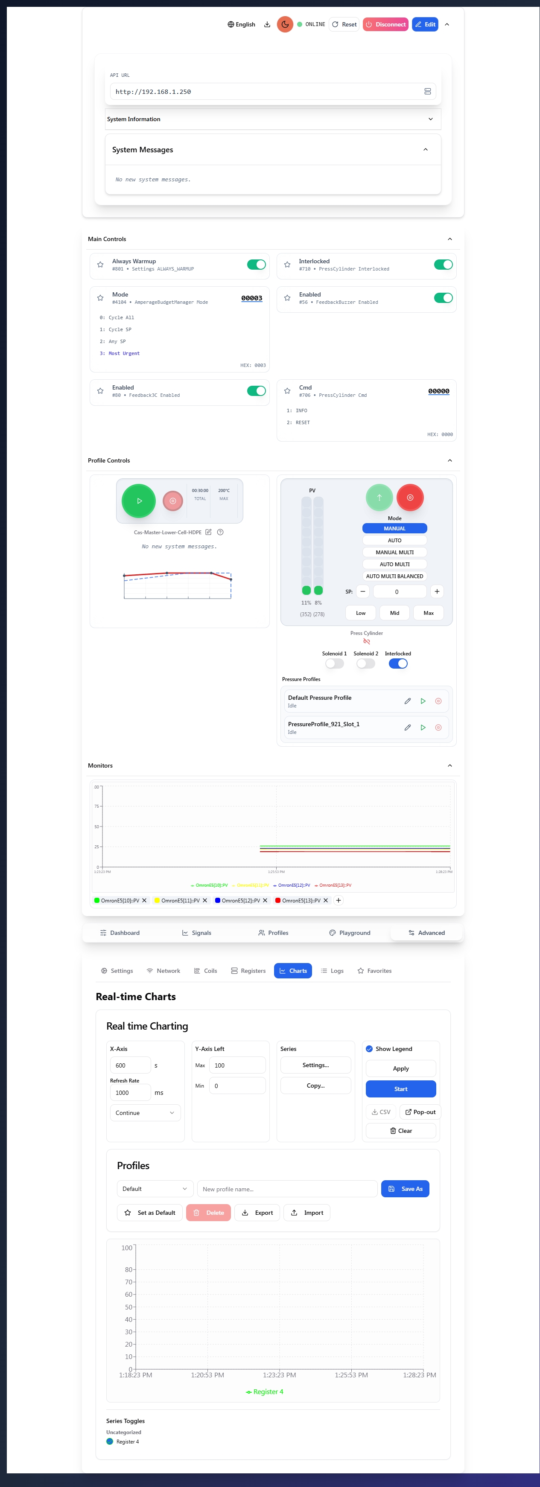
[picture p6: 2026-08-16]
web/packages/modbus-ui/tests/screenshot-advancedcharts.jpg

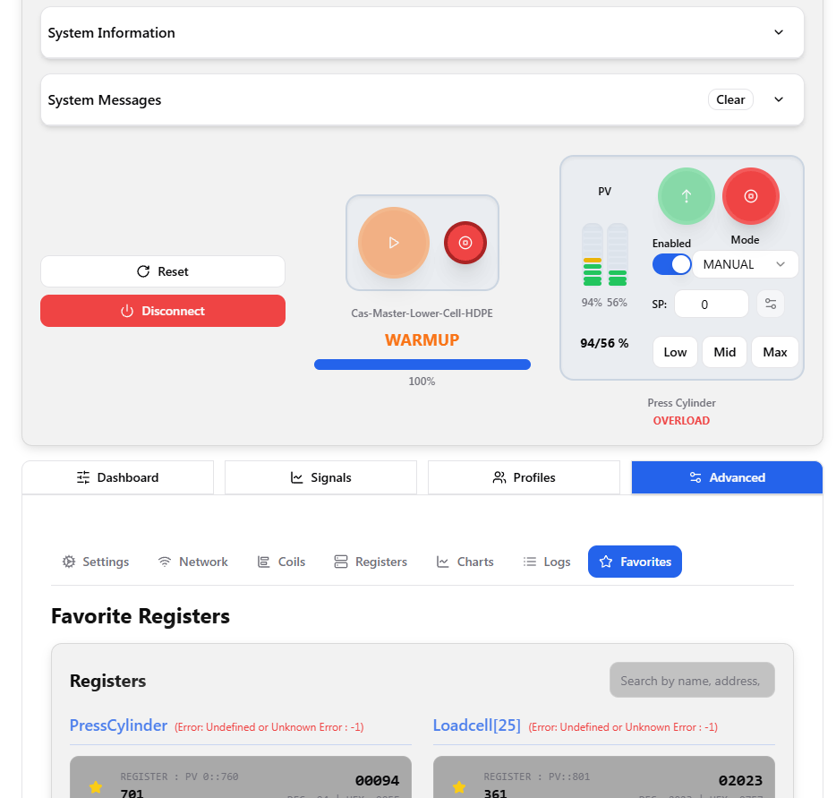
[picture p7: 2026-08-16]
web/packages/modbus-ui/tests/main.png

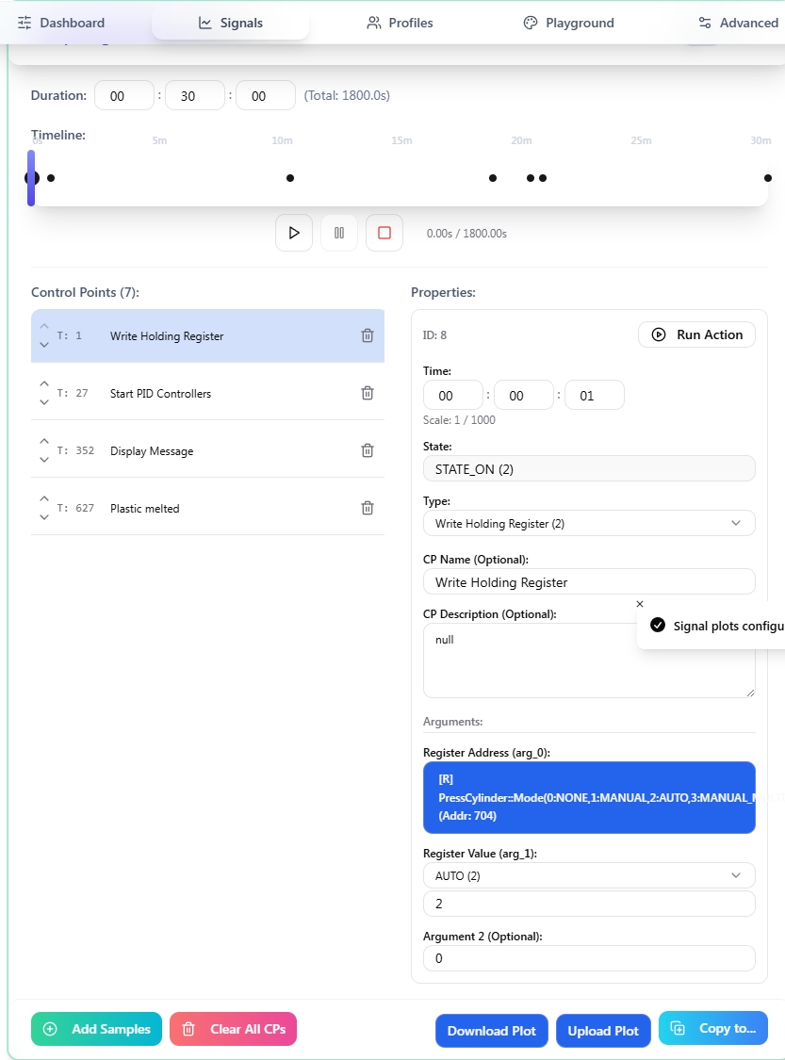
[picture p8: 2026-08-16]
web/packages/modbus-ui/tests/screenshot-signal-plot-editor.jpg

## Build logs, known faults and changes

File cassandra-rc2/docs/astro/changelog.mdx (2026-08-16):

---
title: Change Log
image:
  url: "./main.png"
  alt: "Cassandra Firmware Update"
tags: ["firmware", "update", "release"]
---

import LGallery from "@polymech/astro-base/components/GalleryK.astro";
import RelativeImage from "@polymech/astro-base/components/RelativeImage.astro";
import RelativePicture from "@polymech/astro-base/components/RelativePicture.astro";
import RelativeGallery from "@polymech/astro-base/components/RelativeGallery.astro";
import FileTree from "@polymech/astro-base/components/FileTree.astro";

## v0.6.1 (2025-12-07)

### New Features

- **Pressure Profile Editor**:
  - Launched a dedicated editor for Pressure Profiles w/ Bezier curves.
  - Optimized for 0-100% pressure scaling (removed temperature fields).
  - Added "Edit" shortcut button to Pressure Profile rows for quick access.
- **Pressure Control**:
  - Added `+` and `-` buttons for precise Setpoint adjustment.
  - Hold `Shift` while clicking to adjust by 10 units.
  - Improved layout for better accessibility.

### Improvements

- **Profile Playback**:
  - Fixed duration display for Pressure Profiles (was showing seconds as ms).
  - Updated graph axis labels to "Pressure (%)" for clarity.
- **Modbus Communication**:
  - Implemented `PriorityFilter` to dynamically prioritize critical operations.
  - **Loadcell**: Mandatory read blocks are now flagged as **High Priority** to ensure timely data updates despite bus load.

## v0.6.0 (2025-12-05)

### Breaking Changes

### New Features

- **Timeline Scrubbing**: You can now jump to any point in a profile's timeline using the new slider. This is available in both the Profile Card and the main Playback controls, allowing for quick adjustments to the elapsed time.
- **Pressure Cylinder HOLD**: Double-tapping UP on the joystick now triggers a "HOLD" function. This captures the current pressure as the new setpoint and automatically switches to Auto mode to maintain it. This feature can be enabled/disabled via settings.
- **Settings Memory**: The machine now remembers your "Interlocked" and "Mode" settings for the Pressure Cylinder even after a restart.
- **Pressure Profiles**: There are now 4 instead of 1 pressure profiles.
- **Warmup Notification**: A buzzer now sounds when a temperature profile completes its warmup phase and begins running.
- **Sound feedback for Temperature Profiles**: The machine now makes a sound when a temperature profile warmup phase is completed.

### Improvements & Fixes

- **Pressure Cylinder**:
  - Unified manual control logic for single and multi-cylinder modes, ensuring consistent overload protection.
  - Improved stability of mode transitions and loadcell handling.
- **Visual Feedback**:
  - Added a "Disconnected" icon (crossed-out WiFi) to Controller Cards and Pressure Cylinder controls. This appears immediately if the connection is lost, so you know when data is stale.
  - Added a "Profile" badge to Controller Cards to clearly show which profile is currently active.
  - Enabled buzzer sounds for key profile events.
- **Profile Editor**:
  - Fixed text readability in the description field when using Dark Mode.
  - Optimized button layout for better usability on mobile devices.
- **Safety**:
  - Added safeguards to prevent accidental pressure application when no profile is running.
- **Fixes**:
  - Better handling of disconnected devices over Modbus.
  - Restore IsSlave, ComWrite after reboot.
  - Restore Omon & Temperature profile enabled state after reboot.
  - **Profile Timing**: Fixed an issue where the profile timer would start counting during the warmup phase. The timer now correctly starts only after the profile enters the running state.

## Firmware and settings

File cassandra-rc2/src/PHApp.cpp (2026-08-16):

#include <Arduino.h>
#include <ArduinoLog.h>
#include <Component.h>
#include <enums.h>
#include <macros.h>

#include "./PHApp.h"
#include "./config-modbus.h"
#include "./config.h"
#include "Settings.h"
#include "esp32_compat.h"
#include <components/Logger.h>

#include <components/OmronE5.h>
#include <components/OmronE5Types.h>

#ifdef ENABLE_MODBUS_TCP
#include <modbus/ModbusTCP.h>
#include <modbus/ModbusTypes.h>
#endif

#include <LittleFS.h>
#include <components/RestServer.h>

#if defined(ENABLE_AMPERAGE_BUDGET_MANAGER)
void PHApp_onWarmupComplete(Component *owner) {
  PHApp *app = static_cast<PHApp *>(owner);
  if (app) {
    bool wasInitializing = false;
#ifdef ENABLE_PROFILE_TEMPERATURE
    for (int i = 0; i < PROFILE_TEMPERATURE_COUNT; i++) {
      if (app->tempProfiles[i] != nullptr &&
          app->tempProfiles[i]->getCurrentStatus() ==
              PlotStatus::INITIALIZING) {
        wasInitializing = true;
        break;
      }
    }
#endif

    if (wasInitializing) {
      // TODO: Implement any logic that should occur when the warmup is
      // complete.
      LS_INFO("PHApp received warmup complete notification from "
              "AmperageBudgetManager.");
#ifdef ENABLE_FEEDBACK_BUZZER
      if (app->feedbackBuzzer_0) {
        app->feedbackBuzzer_0->setMode(
            FeedbackBuzzer::E_BuzzerMode::MODE_FAST_BLINK, 3000);
      }
#endif
    }
  }
}
#endif

#define MB_R_APP_STATE_REG 9
#define MB_R_SYSTEM_CMD_PRINT_RESET 1
#define MB_R_SYSTEM_CMD_PRINT_REGS 2
#define MB_R_SYSTEM_CMD_PRINT_MEMORY 5
#define MB_R_SYSTEM_CMD_PRINT_VFD 6

#ifdef ENABLE_PROFILER
uint32_t PHApp::initialFreeHeap = 0;
uint64_t PHApp::initialCpuTicks = 0;
#endif

#ifndef LOG_LEVEL
#define LOG_LEVEL LOG_LEVEL_VERBOSE
#endif
///////////////////////////////////////////////////////////////////////////////////////////////////
//
// Network Servers
//
#if defined(ENABLE_WEBSERVER)
WiFiServer server(80);
#endif

#ifdef ENABLE_MODBUS_TCP
ModbusServerTCPasync mb;
#endif

///////////////////////////////////////////////////////////////////////////////////////////////////
//
// Omron E5
//
#undef ENABLE_TRUTH_COLLECTOR

///////////////////////////////////////////////////////////////////////////////////////////////////
//
// Factory : Instances
//
#define ADD_RELAY(relayNum, relayPin, relayKey, relayAddr)                     \
  relay_##relayNum = new Relay(this, relayPin, relayKey, relayAddr);           \
  components.push_back(relay_##relayNum);

#ifdef ENABLE_SOLENOID_0
#define ADD_SOLENOID(solenoidNum, solenoidPin, solenoidKey, solenoidAddr)      \
  solenoid_##solenoidNum =                                                     \
      new Solenoid(this, solenoidPin, solenoidKey, solenoidAddr);              \
  components.push_back(solenoid_##solenoidNum);
#endif

#define ADD_POT(potNum, potPin, potKey, potAddr, ...)                          \
  pot_##potNum = new POT(this, potPin, potKey, potAddr, ##__VA_ARGS__);        \
  components.push_back(pot_##potNum);

#define ADD_GPIO_CONFIG(configs, gpioPin, gpioAddr, valueName, typeName)       \
  configs.push_back(GPIO_PinConfig(                                            \
      static_cast<E_GPIO_Pin>(gpioPin), MB_GPIO_DEFAULT_TYPE, gpioAddr,        \
      E_FN_CODE::FN_WRITE_COIL, MB_ACCESS_READ_WRITE,                          \
      MB_GPIO_OP_INTERVAL_MS, valueName, "GPIO_Group", typeName));

#define MB_GPIO_TYPE_ENUM_DESC                                                \
  "(0:Unknown,1:Input,2:Output,3:InputPullup,4:InputPulldown,5:OpenDrain,6:Analog,7:Touch)"

#define MB_GPIO_ADDR_FOR_PIN(gpioPin)                                          \
  (MB_GPIO_BASE_ADDR + E_NVC_USER +                                             \
   ((gpioPin) * GPIO_PinConfig::MODBUS_REGISTER_COUNT))

#define ADD_GPIO_ESP32_PIN(configs, gpioPin)                                   \
  ADD_GPIO_CONFIG(configs, gpioPin, MB_GPIO_ADDR_FOR_PIN(gpioPin),             \
                  "GPIO " #gpioPin " Value",                                 \
                  "GPIO " #gpioPin " Type:" MB_GPIO_TYPE_ENUM_DESC)

#define ADD_POS3ANALOG(posNum, switchPin1, switchPin2, switchKey, switchAddr)  \
  pos3Analog_##posNum =                                                        \
      new Pos3Analog(this, switchPin1, switchPin2, switchKey, switchAddr);     \
  components.push_back(pos3Analog_##posNum);

#ifdef ENABLE_PID
#define ADD_PID(pidNum, nameStr, doPin, csPin, clkPin, outPin, key)            \
  pidController_##pidNum =                                                     \
      new PIDController(key, nameStr, doPin, csPin, clkPin, outPin);           \
  components.push_back(pidController_##pidNum);
#endif

Logger *g_logger = nullptr;

void PHApp::printRegisters() {
  L_VERBOSE(F("--- Entering PHApp::printRegisters ---"));

#if ENABLED(HAS_MODBUS_REGISTER_DESCRIPTIONS)
  Log.setShowLevel(false);
  Serial.print("| Name | ID  | Address | RW |  Function Code | Number "
               "Addresses |Register Description| \n");
  Serial.print("|------|----------|----|----|----|----|-------|\n");
  short size = components.size();
  L_VERBOSE(F("PHApp::printRegisters - Processing %d components..."), size);
  for (int i = 0; i < size; i++) {
    Component *component = components[i];
    if (!component) {
      L_ERROR(F("PHApp::printRegisters - Found NULL component at index %d"), i);
      continue;
    }
    L_VERBOSE(F("PHApp::printRegisters - Component %d: ID=%d, Name=%s"), i,
              component->id, component->name.c_str());
    // if (!(component->nFlags & 1 << OBJECT_NET_CAPS::E_NCAPS_MODBUS)) // <--
    // Modbus flag check might be different now
    // {
    //   continue;
    // }
    // Log.verbose("| %s | %d | %d | %s | %d | %d | %s |\n", // <-- Calls to
    // removed ModbusGateway methods
    //             component->name.c_str(),
    //             component->id,
    //             component->getAddress(),
    //             component->getRegisterMode(),
    //             component->getFunctionCode(),
    //             component->getNumberAddresses(),
    //             component->getRegisterDescription().c_str());
    Log.verbose("| %s | %d | - | - | - | - | - |\n", // <-- Simplified output
                component->name.c_str(), component->id);
  }
  Log.setShowLevel(true);
#endif
  L_VERBOSE(F("--- Exiting PHApp::printRegisters ---"));
}
short PHApp::reset(short val0, short val1) {
  _state = APP_STATE::RESET;
  _error = E_OK;

#if defined(ESP32) ||                                                          \
    defined(ESP8266) // Use ESP.restart() for ESP32 and ESP8266
  ESP.restart();
#else
  return E_NOT_IMPLEMENTED;
#endif
  return E_OK;
}
short PHApp::list(short val0, short val1) {
  uchar s = components.size();
  for (uchar i = 0; i < s; i++) {
    Component *component = components[i];
    if (component) {
      L_VERBOSE("PHApp::list - %d | %s (ID: %d)", i, component->name.c_str(),
                component->id);
    } else {
      Log.warningln("PHApp::list - NULL component at index %d", i);
    }
  }
  return E_OK;
}
short PHApp::setup() {
  _state = APP_STATE::RESET;
  _error = E_OK;
#ifdef ENABLE_PROFILER
  if (initialFreeHeap == 0 && initialCpuTicks == 0) {
    initialFreeHeap = ESP.getFreeHeap();
    initialCpuTicks = esp_cpu_get_cycle_count();
  }
#endif

#ifndef DISABLE_SERIAL_LOGGING
  // Serial Setup
  Serial.begin(SERIAL_BAUD_RATE);
  while (!Serial && !Serial.available()) {
  }
#endif

#ifdef ENABLE_LOGGER
  logger_0 = new Logger(this, COMPONENT_KEY_LOGGER, MB_ADDR_LOGGER_0);
  g_logger = logger_0;
  components.push_back(logger_0);
#endif

#ifndef DISABLE_SERIAL_LOGGING
  // Log Setup
#if defined(ENABLE_LOGGER)
#if defined(ENABLE_LOGGING_TARGET_PRINT)
  if (logger_0) {
    Serial.begin(SERIAL_BAUD_RATE);
    logger_0->addPrintTarget(&Serial);
  }
#endif
  Log.begin(LOG_LEVEL, logger_0);
#else
  Log.begin(LOG_LEVEL, &Serial);
#endif
  Log.setShowLevel(true);
#else
  // Log Setup (without Serial)
  Log.begin(LOG_LEVEL_WARNING, nullptr);
  Log.setShowLevel(false);
#endif

  L_INFO("PHApp::setup() started. Logger configured.");

  // Application stuff
#ifdef ENABLE_RUNTIME_STATE
  runtimeState = new RuntimeState(this, COMPONENT_KEY_RUNTIME_STATE);
  components.push_back(runtimeState);
#endif

// Components
#ifdef ENABLE_SERIAL_BRIDGE
  bridge = new Bridge(this);
  components.push_back(bridge);
#endif
#ifndef DISABLE_SERIAL_LOGGING
  com_serial = new SerialMessage(Serial, bridge);
  components.push_back(com_serial);
#endif
  // Network
  short networkSetupResult = setupNetwork();
  if (networkSetupResult != E_OK) {
    L_ERROR("Network setup failed with error code: %d", networkSetupResult);
  }

#ifdef ENABLE_SETTINGS
  appSettings = new Settings(this);
  components.push_back(appSettings);

#endif

#ifdef ENABLE_LOGGER
#if defined(ENABLE_LOGGING_TARGET_WEBSOCKET) && defined(ENABLE_WEBSERVER) &&   \
    defined(ENABLE_WEBSOCKET)
  if (logger_0 && webServer) {
    logger_0->addWebSocketTarget(webServer);
    L_INFO("WebSocket logging target added.");
  }
#endif
#if defined(ENABLE_LOGGING_TARGET_FILE) && defined(ENABLE_LITTLEFS)
  if (logger_0) {
    logger_0->addFileTarget();
    L_INFO("File logging target added.");
  }
#endif
#endif

  // Components
#ifdef ENABLE_RELAYS
#ifdef AUX_RELAY_0
  ADD_RELAY(0, AUX_RELAY_0, COMPONENT_KEY_RELAY_0, MB_ADDR_AUX_5);
#endif
#ifdef AUX_RELAY_1
  ADD_RELAY(1, AUX_RELAY_1, COMPONENT_KEY_RELAY_1, MB_ADDR_AUX_6);
#endif
#endif

#ifdef ENABLE_POT0
  ADD_POT(0, MB_ANALOG_0, COMPONENT_KEY_ANALOG_0, MB_ADDR_AUX_2,
          POTDampingAlgorithm::DAMPING_EMA, true);
#endif

#ifdef ENABLE_POT1
  ADD_POT(1, MB_ANALOG_1, COMPONENT_KEY_ANALOG_1, MB_ADDR_AUX_3,
          POTDampingAlgorithm::DAMPING_EMA, true);
#endif

#if (defined(AUX_ANALOG_3POS_SWITCH_0) && (defined(AUX_ANALOG_3POS_SWITCH_1)))
  ADD_POS3ANALOG(0, AUX_ANALOG_3POS_SWITCH_0, AUX_ANALOG_3POS_SWITCH_1,
                 COMPONENT_KEY_MB_ANALOG_3POS_SWITCH_0, MB_ADDR_AUX_3);
#endif

#if (defined(MB_ANALOG_3POS_SWITCH_2) && (defined(MB_ANALOG_3POS_SWITCH_3)))
  // ADD_POS3ANALOG(1, MB_ANALOG_3POS_SWITCH_2, MB_ANALOG_3POS_SWITCH_3,
  // COMPONENT_KEY_MB_ANALOG_3POS_SWITCH_1, MB_R_SWITCH_1); // <-- Temporarily
  // disable
#endif

#ifdef ENABLE_MB_GPIO
#ifndef MB_GPIO_OP_INTERVAL_MS
#define MB_GPIO_OP_INTERVAL_MS 100
#endif
#ifndef MB_GPIO_DEFAULT_TYPE
#define MB_GPIO_DEFAULT_TYPE E_GPIO_TYPE_INPUT
#endif
#ifndef MB_GPIO_BASE_ADDR
#define MB_GPIO_BASE_ADDR 300
#endif
  std::vector<GPIO_PinConfig> gpioConfigs;
#ifdef MB_GPIO_ALL_ESP32_PINS
  gpioConfigs.reserve(34);
  ADD_GPIO_ESP32_PIN(gpioConfigs, 0);
  ADD_GPIO_ESP32_PIN(gpioConfigs, 1);
  ADD_GPIO_ESP32_PIN(gpioConfigs, 2);
  ADD_GPIO_ESP32_PIN(gpioConfigs, 3);
  ADD_GPIO_ESP32_PIN(gpioConfigs, 4);
  ADD_GPIO_ESP32_PIN(gpioConfigs, 5);
  ADD_GPIO_ESP32_PIN(gpioConfigs, 6);
#ifndef ENABLE_POT1
  ADD_GPIO_ESP32_PIN(gpioConfigs, 7);
#endif
  ADD_GPIO_ESP32_PIN(gpioConfigs, 8);
  ADD_GPIO_ESP32_PIN(gpioConfigs, 9);
  ADD_GPIO_ESP32_PIN(gpioConfigs, 10);
  ADD_GPIO_ESP32_PIN(gpioConfigs, 11);
  ADD_GPIO_ESP32_PIN(gpioConfigs, 12);
  ADD_GPIO_ESP32_PIN(gpioConfigs, 13);
#ifndef ENABLE_OPERATOR_SWITCH
  ADD_GPIO_ESP32_PIN(gpioConfigs, 14);
#endif
#if !defined(ENABLE_POT0) && !defined(ENABLE_OPERATOR_SWITCH)
  ADD_GPIO_ESP32_PIN(gpioConfigs, 15);
#endif
#ifndef PIN_AUX_1
  ADD_GPIO_ESP32_PIN(gpioConfigs, 16);
#endif
#ifndef ENABLE_RS485
  ADD_GPIO_ESP32_PIN(gpioConfigs, 17);
  ADD_GPIO_ESP32_PIN(gpioConfigs, 18);
#endif
  ADD_GPIO_ESP32_PIN(gpioConfigs, 19);
  ADD_GPIO_ESP32_PIN(gpioConfigs, 20);
  ADD_GPIO_ESP32_PIN(gpioConfigs, 21);
  ADD_GPIO_ESP32_PIN(gpioConfigs, 35);
  ADD_GPIO_ESP32_PIN(gpioConfigs, 36);
  ADD_GPIO_ESP32_PIN(gpioConfigs, 37);
  ADD_GPIO_ESP32_PIN(gpioConfigs, 38);
#ifndef ENABLE_JOYSTICK
  ADD_GPIO_ESP32_PIN(gpioConfigs, 39);
  ADD_GPIO_ESP32_PIN(gpioConfigs, 40);
#endif
  ADD_GPIO_ESP32_PIN(gpioConfigs, 41);
  ADD_GPIO_ESP32_PIN(gpioConfigs, 42);
  ADD_GPIO_ESP32_PIN(gpioConfigs, 43);
  ADD_GPIO_ESP32_PIN(gpioConfigs, 44);
  ADD_GPIO_ESP32_PIN(gpioConfigs, 45);
  ADD_GPIO_ESP32_PIN(gpioConfigs, 46);
  ADD_GPIO_ESP32_PIN(gpioConfigs, 47);
  ADD_GPIO_ESP32_PIN(gpioConfigs, 48);
#else
  gpioConfigs.reserve(6);
#ifdef MB_GPIO_ADDR_CH1
  ADD_GPIO_CONFIG(gpioConfigs, GPIO_PIN_CH1, MB_GPIO_ADDR_CH1, "GPIO CH1 Value",
                  "GPIO CH1 Type:" MB_GPIO_TYPE_ENUM_DESC);
#endif
#ifdef MB_GPIO_ADDR_CH2
  ADD_GPIO_CONFIG(gpioConfigs, GPIO_PIN_CH2, MB_GPIO_ADDR_CH2, "GPIO CH2 Value",
                  "GPIO CH2 Type:" MB_GPIO_TYPE_ENUM_DESC);
#endif
#ifdef MB_GPIO_ADDR_CH3
  ADD_GPIO_CONFIG(gpioConfigs, GPIO_PIN_CH3, MB_GPIO_ADDR_CH3, "GPIO CH3 Value",
                  "GPIO CH3 Type:" MB_GPIO_TYPE_ENUM_DESC);
#endif
#ifdef MB_GPIO_ADDR_CH4
  ADD_GPIO_CONFIG(gpioConfigs, GPIO_PIN_CH4, MB_GPIO_ADDR_CH4, "GPIO CH4 Value",
                  "GPIO CH4 Type:" MB_GPIO_TYPE_ENUM_DESC);
#endif
#ifdef MB_GPIO_ADDR_CH5
  ADD_GPIO_CONFIG(gpioConfigs, GPIO_PIN_CH5, MB_GPIO_ADDR_CH5, "GPIO CH5 Value",
                  "GPIO CH5 Type:" MB_GPIO_TYPE_ENUM_DESC);
#endif
#ifdef MB_GPIO_ADDR_CH6
  ADD_GPIO_CONFIG(gpioConfigs, GPIO_PIN_CH6, MB_GPIO_ADDR_CH6, "GPIO CH6 Value",
                  "GPIO CH6 Type:" MB_GPIO_TYPE_ENUM_DESC);
#endif
#endif
  if (!gpioConfigs.empty()) {
    gpio_0 =
        new MB_GPIO(this, COMPONENT_KEY_GPIO_MAP, MB_GPIO_BASE_ADDR, gpioConfigs);
    components.push_back(gpio_0);
  }
#endif

#ifdef PIN_ANALOG_LEVEL_SWITCH_0
  analogLevelSwitch_0 =
      new AnalogLevelSwitch(this,                      // owner
                            PIN_ANALOG_LEVEL_SWITCH_0, // analogPin
                            ALS_0_NUM_LEVELS,          // numLevels
                            ALS_0_ADC_STEP,            // levelStep
                            ALS_0_ADC_OFFSET,          // adcValueOffset
                            ID_ANALOG_LEVEL_SWITCH_0,  // id
                            ALS_0_MB_ADDR              // modbusAddress
      );
  if (analogLevelSwitch_0) {
    components.push_back(analogLevelSwitch_0);
    L_INFO(F("AnalogLevelSwitch_0 initialized. Pin:%d, ID:%d, Levels:%d, "
             "Step:%d, Offset:%d, Smooth:%d(Fixed), Debounce:%d(Fixed), MB:%d"),
           PIN_ANALOG_LEVEL_SWITCH_0, ID_ANALOG_LEVEL_SWITCH_0,
           ALS_0_NUM_LEVELS, ALS_0_ADC_STEP, ALS_0_ADC_OFFSET,
           ALS_SMOOTHING_SIZE, ALS_DEBOUNCE_COUNT, ALS_0_MB_ADDR);
  } else {
    L_ERROR(F("AnalogLevelSwitch_0 initialization failed."));
  }
#endif

#ifdef ENABLE_STATUS
  statusLight_0 = new StatusLight(
      this, STATUS_WARNING_PIN, COMPONENT_KEY_FEEDBACK_0,
      MB_MONITORING_STATUS_FEEDBACK_0); // Keep original address for now, add to
                                        // config-modbus.h later if needed
  components.push_back(statusLight_0);
  statusLight_1 = new StatusLight(
      this, STATUS_ERROR_PIN, COMPONENT_KEY_FEEDBACK_1,
      MB_MONITORING_STATUS_FEEDBACK_1); // Keep original address for now
  components.push_back(statusLight_1);
#else
  statusLight_0 = NULL;
  statusLight_1 = NULL;
#endif
  L_INFO("PHApp::setup - Base App::setup() called.");

#ifdef PIN_LED_FEEDBACK_0
  ledFeedback_0 = new LEDFeedback(this,                  // owner
                                  PIN_LED_FEEDBACK_0,    // pin
                                  LED_PIXEL_COUNT_0,     // pixelCount
                                  ID_LED_FEEDBACK_0,     // id
                                  LED_FEEDBACK_0_MB_ADDR // modbusAddress
  );
  if (ledFeedback_0) {
    components.push_back(ledFeedback_0);
    L_INFO(F("LEDFeedback_0 initialized. Pin:%d, Count:%d, ID:%d, MB:%d"),
           PIN_LED_FEEDBACK_0, LED_PIXEL_COUNT_0, ID_LED_FEEDBACK_0,
           LED_FEEDBACK_0_MB_ADDR);
  } else {
    L_ERROR(F("LEDFeedback_0 initialization failed."));
  }
#endif

#ifdef ENABLE_JOYSTICK
  joystick_0 = new Joystick(this,               // owner
                            PIN_JOYSTICK_UP,    // UP pin
                            PIN_JOYSTICK_DOWN,  // DOWN pin
                            PIN_JOYSTICK_LEFT,  // LEFT pin
                            PIN_JOYSTICK_RIGHT, // RIGHT pin
                            MB_ADDR_AUX_7       // modbusAddress
  );
  if (joystick_0) {
    components.push_back(joystick_0);
  } else {
    L_ERROR(F("Joystick_0 initialization failed."));
  }
#endif

#ifdef PIN_AUX_1

  pushButton_1 = new PushButton(this, PIN_AUX_1, COMPONENT_KEY_PUSH_BUTTON_0,
                                MB_IREG_ANALOG_0);
  components.push_back(pushButton_1);

#endif

#ifdef ENABLE_FEEDBACK_3C
  feedback3C_0 = new Feedback3C(this, GPIO_PIN_CH4, GPIO_PIN_CH5, GPIO_PIN_CH6,
                                COMPONENT_KEY_FEEDBACK_0, MB_ADDR_FEEDBACK_0);
  components.push_back(feedback3C_0);
#endif

#ifdef ENABLE_FEEDBACK_BUZZER
  feedbackBuzzer_0 = new FeedbackBuzzer(
      this, GPIO_PIN_CH3, COMPONENT_KEY_FEEDBACK_1, MB_ADDR_AUX_9);
  components.push_back(feedbackBuzzer_0);
#endif

// Systems : Hydraulic Cylinder - Loadcell sensor - RS485
#ifdef ENABLE_SOLENOID_0
  uint32_t solenoid0Addr =
      appSettings->get("SOLENOID_0_MB_ADDR", (uint32_t)MB_ADDR_SOLENOID_0);
  ADD_SOLENOID(0, PIN_SOLENOID_0, COMPONENT_KEY_SOLENOID_0, solenoid0Addr);
#endif

#ifdef ENABLE_SOLENOID_1
  uint32_t solenoid1Addr =
      appSettings->get("SOLENOID_1_MB_ADDR", (uint32_t)MB_ADDR_SOLENOID_1);
  ADD_SOLENOID(1, PIN_SOLENOID_1, COMPONENT_KEY_SOLENOID_1, MB_ADDR_SOLENOID_1);
#endif

#ifdef ENABLE_LOADCELL_0
  uint32_t slaveId0 =
      appSettings->get("LOADCELL_SLAVE_ID_0", (uint32_t)LOADCELL_SLAVE_ID_0);
  loadCell_0 = new Loadcell(this, slaveId0, LOADCELL_READ_INTERVAL,
                            COMPONENT_KEY_LOADCELL_0);
  components.push_back(static_cast<RTU_Base *>(loadCell_0));
#endif

#ifdef ENABLE_LOADCELL_1
  uint32_t slaveId1 =
      appSettings->get("LOADCELL_SLAVE_ID_1", (uint32_t)LOADCELL_SLAVE_ID_1);
  loadCell_1 = new Loadcell(this, slaveId1, LOADCELL_READ_INTERVAL,
                            COMPONENT_KEY_LOADCELL_1);
  components.push_back(static_cast<RTU_Base *>(loadCell_1));
#endif

#ifdef ENABLE_PRESS_CYLINDER
  pressCylinder_0 =
      new PressCylinder(this, COMPONENT_KEY_PRESS_CYLINDER_0,
                        MB_ADDR_PRESS_CYLINDER_0, joystick_0, pushButton_1);
#ifdef ENABLE_LOADCELL_0
  if (loadCell_0)
    pressCylinder_0->addLoadcell(loadCell_0);
#endif
#ifdef ENABLE_LOADCELL_1
  if (loadCell_1)
    pressCylinder_0->addLoadcell(loadCell_1);
#endif
#ifdef ENABLE_SOLENOID_0
  if (solenoid_0)
    pressCylinder_0->addSolenoid(solenoid_0);
#endif
#ifdef ENABLE_SOLENOID_1
  if (solenoid_1)
    pressCylinder_0->addSolenoid(solenoid_1);
#endif
  components.push_back(pressCylinder_0);
#endif

#ifdef ENABLE_OPERATOR_SWITCH
  operatorSwitch_0 = new OperatorSwitch(
      this, PIN_OPERATOR_SWITCH_STOP, PIN_OPERATOR_SWITCH_CYCLE,
      COMPONENT_KEY_OPERATOR_SWITCH, MB_ADDR_AUX_8);
  components.push_back(operatorSwitch_0);
#endif

#ifdef ENABLE_MODBUS_MIRROR
  modbusMirror_0 = new ModbusMirror(this, COMPONENT_KEY_MODBUS_MIRROR);
  components.push_back(modbusMirror_0);
#endif

#ifdef ENABLE_IFTTT
  iftttWebhook = new IFTTTWebhook(this, COMPONENT_KEY_IFTTT);
  components.push_back(iftttWebhook);
#endif

#ifdef ENABLE_NETWORK_VALUE_TEST
  L_INFO("PHApp::setup - Initializing NetworkValueTest...");
  networkValueTest =
      new NetworkValueTest(this, COMPONENT_KEY_TEST_NV, MB_ADDR_AUX_TEST_NV);
  networkValueTest->owner = this;
  components.push_back(networkValueTest);
#endif

#ifdef ENABLE_NETWORK_VALUE_TEST_PB
  L_INFO("PHApp::setup - Initializing NetworkValueTestPB...");
  networkValueTestPB = new NetworkValueTestPB(this, COMPONENT_KEY_TEST_NV_PB,
                                              MB_ADDR_AUX_TEST_NV + 10);
  networkValueTestPB->owner = this;
  components.push_back(networkValueTestPB);
#endif

  // Motors
#ifdef ENABLE_SAKO_VFD
  vfd_0 = new SAKO_VFD(this, MB_SAKO_VFD_SLAVE_ID, MB_SAKO_VFD_READ_INTERVAL);
  components.push_back(vfd_0);
#endif

#ifdef ENABLE_DELTA_VFD
  vfd_2 =
      new DELTA_VFD(this, MB_DELTA_VFD_SLAVE_ID, MB_DELTA_VFD_READ_INTERVAL);
  components.push_back(vfd_2);
#endif

  // Temperature
#ifdef ENABLE_PROFILE_TEMPERATURE
  for (ushort i = 0; i < PROFILE_TEMPERATURE_COUNT; ++i) {
    // Assign unique ID: COMPONENT_KEY_PROFILE_START (910) + slot index
    ushort profileComponentId = COMPONENT_KEY_PROFILE_START + i;
    ushort baseAddr =
        MB_HREG_TEMP_PROFILE_BASE + (i * TEMP_PROFILE_REGISTER_COUNT);
    tempProfiles[i] =
        new TemperatureProfile(this, i, profileComponentId, baseAddr);
    tempProfiles[i]->setEventsDelegate(this);
    components.push_back(tempProfiles[i]);
  }

#endif

#ifdef ENABLE_PROFILE_PRESSURE
  for (ushort i = 0; i < PROFILE_PRESSURE_COUNT; ++i) {
    ushort profileComponentId = COMPONENT_KEY_PRESSURE_PROFILE_START + i;
    ushort baseAddr =
        MB_HREG_PRESSURE_PROFILE_BASE + (i * PRESSURE_PROFILE_REGISTER_COUNT);
    pressureProfiles[i] =
        new PressureProfile(this, i, profileComponentId, baseAddr);
    pressureProfiles[i]->setEventsDelegate(this);
    components.push_back(pressureProfiles[i]);
  }
#endif

#ifdef ENABLE_PROFILE_SIGNAL_PLOT
  for (int i = 0; i < PROFILE_SIGNAL_PLOT_COUNT; i++) {
    ushort profileComponentId = COMPONENT_KEY_SIGNAL_PLOT_START + i;
    ushort modbusAddress =
        MB_HREG_SIGNAL_PLOT_BASE + (i * SIGNAL_PLOT_REGISTER_COUNT);
    signalPlots[i] = new SignalPlot(this, i, profileComponentId, modbusAddress);
    signalPlots[i]->setEventsDelegate(this);
    components.push_back(signalPlots[i]);
#ifdef ENABLE_MODBUS_TCP
    if (modbusManager != nullptr) {
      signalPlots[i]->setModbusTCP(modbusManager);
    } else {
      L_ERROR("PHApp::setup - SignalPlot %d: modbusManager is nullptr", i);
    }
#endif
  }
#endif
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
void app_main() {
  // Arduino will still call setup()/loop()
}

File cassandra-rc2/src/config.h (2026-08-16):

#ifndef CONFIG_H
#define CONFIG_H

#include <Arduino.h>
#include <stdint.h>

#include "config_adv.h"

///////////////////////////////////////////////////////////////////////////////////////////////////
//
// 1. Core System
//
///////////////////////////////////////////////////////////////////////////////////////////////////

///////////////////////////////////////////////////////
//
// Overrides

// #define WS_MAX_QUEUED_MESSAGES 128
// #define ENABLE_COMPONENT_STATS

///////////////////////////////////////////////////////////////////////////////////////////////////
//
// 2. Platform
//
///////////////////////////////////////////////////////////////////////////////////////////////////

////////////////////////////////////////////////////////////////////////////////
//
// Component IDs
//
typedef enum COMPONENT_KEY {
  COMPONENT_KEY_LOGGER = 10,
  COMPONENT_KEY_SETTINGS = 11,
  COMPONENT_KEY_RUNTIME_STATE = 250,
  COMPONENT_KEY_RELAY_0 = 300,
  COMPONENT_KEY_RELAY_1 = 301,
  COMPONENT_KEY_RELAY_2 = 302,
  COMPONENT_KEY_RELAY_3 = 303,
  COMPONENT_KEY_RELAY_4 = 304,
  COMPONENT_KEY_RELAY_5 = 305,
  COMPONENT_KEY_SOLENOID_0 = 310,
  COMPONENT_KEY_SOLENOID_1 = 311,
  COMPONENT_KEY_PID_0 = 100,
  COMPONENT_KEY_PID_1 = 101,
  COMPONENT_KEY_PID_2 = 102,
  COMPONENT_KEY_ANALOG_0 = 350,
  COMPONENT_KEY_ANALOG_1 = 351,
  COMPONENT_KEY_ANALOG_2 = 352,
  COMPONENT_KEY_LOADCELL_0 = 360,
  COMPONENT_KEY_LOADCELL_1 = 361,
  COMPONENT_KEY_ANALOG_3POS_SWITCH_0 = 420,
  COMPONENT_KEY_ANALOG_3POS_SWITCH_1 = 421,
  COMPONENT_KEY_ANALOG_LEVEL_SWITCH_0 = 450,
  COMPONENT_KEY_ANALOG_LEVEL_SWITCH_1 = 451,
  COMPONENT_KEY_JOYSTICK_0 = 500,
  COMPONENT_KEY_PUSH_BUTTON_0 = 510,
  COMPONENT_KEY_STEPPER_0 = 601,
  COMPONENT_KEY_STEPPER_1 = 602,
  COMPONENT_KEY_PID = 620,
  COMPONENT_KEY_EXTRUDER = 650,
  COMPONENT_KEY_PLUNGER = 670,
  COMPONENT_KEY_FEEDBACK_0 = 701,
  COMPONENT_KEY_FEEDBACK_1 = 730,
  COMPONENT_KEY_FEEDBACK_2 = 740,
  COMPONENT_KEY_PRESS_CYLINDER_0 = 760,
  COMPONENT_KEY_SAKO_VFD = 750,
  COMPONENT_KEY_DELTA_VFD = 752,
  COMPONENT_KEY_HY_VFD = 761,
  COMPONENT_KEY_RS485_TESTER = 800,
  COMPONENT_KEY_RS485 = 801,
  COMPONENT_KEY_AMPERAGE_BUDGET_MANAGER = 850,
  COMPONENT_KEY_GPIO_MAP = 810,
  COMPONENT_KEY_REST_SERVER = 900,
  COMPONENT_KEY_PROFILE_START = 910,
  COMPONENT_KEY_PRESSURE_PROFILE_START = 920,
  COMPONENT_KEY_SIGNAL_PLOT_START = 920,
  COMPONENT_KEY_END = 1000,
  COMPONENT_KEY_TEST_NV = 1001,
  COMPONENT_KEY_OPERATOR_SWITCH = 1002,
  COMPONENT_KEY_TEST_NV_PB = 1003,
  COMPONENT_KEY_MODBUS_MIRROR = 2000,
  COMPONENT_KEY_INFLUXDB = 2001,
} COMPONENT_KEY;

////////////////////////////////////////////////////////////////////////////////
//
// Platform

// Automatic platform detection
#if defined(ARDUINO_PORTENTA_H7_M7)
#define PLATFORM_PORTENTA_H7_M7
#define BOARD_NAME "Portenta H7 M7"
#include <Arduino_MachineControl.h>
using namespace machinecontrol;
#elif defined(ARDUINO_CONTROLLINO_MEGA)
#define PLATFORM_CONTROLLINO_MEGA
#define BOARD_NAME "Controllino Mega"
#include <Controllino.h>
#elif defined(ESP32)
#define PLATFORM_ESP32
#define BOARD_NAME "ESP32"
#elif defined(ARDUINO_AVR_UNO) // Detect Arduino Uno
#define PLATFORM_ARDUINO_UNO
#define BOARD_NAME "Arduino Uno"
#else
#error "Unsupported platform"
#endif

////////////////////////////////////////////////////////////////////////////////
//
// Debugging
#ifndef DISABLE_SERIAL_LOGGING
// Serial Bridge Debugging Switches
// #x #define BRIDGE_DEBUG_REGISTER
// #x #define BRIDGE_DEBUG_CALL_METHOD
// Serial Command Messaging Debugging Switches
// #x #define DEBUG_MESSAGES_PARSE
#endif
//////////////////////////////////////////////////////////////////////////////////////////////////////////////////////////////////////////////////
//
// App Features

// When printing Modbus registers (via serial), print register descriptions
// #define HAS_MODBUS_REGISTER_DESCRIPTIONS 1

///////////////////////////////////////////////////////
//
// Status Feedback Settings

#define STATUS_WARNING_PIN GPIO_PIN_CH6
#define STATUS_ERROR_PIN GPIO_PIN_CH5
#define STATUS_BLINK_INTERVAL 800

///////////////////////////////////////////////////////
//
// Serial Settings
/** @brief Serial port baud rate */
#define SERIAL_BAUD_RATE 38400
/** @brief Parse commands every 100ms */
#define SERIAL_COMMAND_PARSE_INTERVAL 200
// #define ENABLE_SERIAL_BRIDGE
#define LOOP_CYCLE_INTERVAL 1

#define RUNTIME_STATE_FILENAME "/runtime.json"
#define RUNTIME_STATE_SAVE_INTERVAL 10000
#define FILESYSTEM_WRITE_GRACE_PERIOD_MS 500
////////////////////////////////////////////////////////////////
//
// Auxiliary Settings : Relays
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

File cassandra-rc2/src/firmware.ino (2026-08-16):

#ifndef LOG_LEVEL
#define LOG_LEVEL LOG_LEVEL_VERBOSE
#endif

// #define WS_MAX_QUEUED_MESSAGES 512

#include <Arduino.h>

#include <ArduinoLog.h>
#include <Component.h>
#include <App.h>
#include <CommandMessage.h>
#include <Bridge.h>
#include <SerialMessage.h>

#include "config.h"
#include "macros.h"
#include "xtypes.h"
#include "StringUtils.h"

#include "PHApp.h"

PHApp testApp;
void setup()
{
  testApp.setup();
}

void loop()
{
  testApp.loop();
}

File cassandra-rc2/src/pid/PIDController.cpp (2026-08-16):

#ifdef ENABLE_PID
#include "pid/PIDController.h"
#include <ArduinoLog.h>
#include <modbus/ModbusTCP.h>

PIDController::PIDController(uint8_t id, const char *name, int8_t thermoDO, int8_t thermoCS, int8_t thermoCLK, int8_t outputPin)
    : Component(name, id),
      thermocouple(thermoCLK, thermoCS, thermoDO), // CLK, CS, DO
      _thermoDO(thermoDO), _thermoCS(thermoCS), _thermoCLK(thermoCLK),
      _setpoint(25.0), _input(0.0), _output(0.0),                 // Default setpoint
      _kp(2.0), _ki(5.0), _kd(1.0),                               // Default PID gains (example values)
      _pid(&_input, &_output, &_setpoint, _kp, _ki, _kd, DIRECT), // DIRECT or REVERSE depending on heating/cooling
      _aTune(&_input, &_output),
      _autotuning(false),
      _autotuneStatus(AUTOTUNE_OFF),
      _aTuneStartValue(0.0),
      _aTuneNoiseBand(0.5),  // Noise band for autotune (adjust based on system)
      _aTuneLookbackSec(20), // Autotune lookback seconds (adjust)
      _lastKp(0.0), _lastKi(0.0), _lastKd(0.0),
      _outputPin(outputPin),
      _windowStartTime(0),
      _pidModeAuto(false), // Start in MANUAL mode
      _sensorError(false)
{
}

PIDController::~PIDController()
{
    // Nothing specific to delete here
}

short PIDController::setup()
{
    L_INFO("Setting up PIDController '%s'...", name);
    pinMode(_outputPin, OUTPUT);
    digitalWrite(_outputPin, LOW); // Ensure output is off initially

    // Initialize PID
    _pid.SetOutputLimits(0, 255);    // PID output range (for PWM-like control)
    _pid.SetSampleTime(_windowSize); // Set PID sample time = window size
    setPIDMode(_pidModeAuto);        // Apply initial mode

    // Initialize Autotune
    _aTune.SetNoiseBand(_aTuneNoiseBand);
    _aTune.SetOutputStep(100); // Example output step for autotune
    _aTune.SetLookbackSec(_aTuneLookbackSec);
    _aTune.SetControlType(1); // PID type

    // Wait for MAX6675 to stabilize (optional, may remove if blocking is bad)
    delay(500);
    updateTemperature(); // Initial temperature read
    if (_sensorError)
    {
        L_ERROR("PID %s: Initial thermocouple read failed!", name);
    }
    else
    {
        L_INFO("PID %s: Initial temp = %.2f C", name, _input);
    }

    _windowStartTime = millis(); // Initialize window timing
    L_INFO("PIDController '%s' setup complete.", name);
    return E_OK;
}

short PIDController::loop()
{
    unsigned long now = millis();

    updateTemperature(); // Read temperature input

    if (_autotuning)
    {
        runAutotune();
    }
    else if (_pidModeAuto)
    {
        if (!_sensorError)
        {
            _pid.Compute(); // Only compute if temperature reading is valid
        }
        else
        {
            _output = 0; // Turn off output if sensor fails
        }
    }
    // In MANUAL mode, _output is set via Modbus and not changed here

    applyOutput(); // Apply the calculated or manually set output
    return E_OK;
}

void PIDController::updateTemperature()
{
    double temp = thermocouple.readCelsius();
    if (isnan(temp))
    {
        if (!_sensorError)
        { // Log only on transition to error state
            L_ERROR("PID %s: Failed to read temperature from MAX6675!", name);
            _sensorError = true;
            _input = -999.0; // Indicate error state clearly
            // Optionally handle sensor error (e.g., turn off PID, set alarm)
            setPIDMode(false); // Force manual mode on sensor error
        }
    }
    else
    {
        if (_sensorError)
        { // Log recovery
            Log.noticeln("PID %s: Thermocouple reading recovered.", name);
        }
        _sensorError = false;
        _input = temp;
    }
}

void PIDController::runAutotune()
{
    unsigned long now = millis();
    if (!_autotuning)
        return; // Should not happen, but safety check

    byte val = _aTune.Runtime();
    if (val != 0)
    { // Autotune finished
        bool success = (val == 1);
        finishAutotune(success);
    }
    else
    {
        // Autotune still running, apply its output directly
        applyOutput(); // Use the _output value calculated by aTune.Runtime()
    }
}

void PIDController::applyOutput()
{
    unsigned long now = millis();
    // Time-proportional output control (PWM-like over _windowSize)
    if (now - _windowStartTime > _windowSize)
    {
        _windowStartTime += _windowSize;
    }

    double currentOutput = _autotuning ? _output : (_pidModeAuto ? _output : _output); // Use ATune output if running, else PID/Manual output

    // Map 0-255 output to on/off time within the window
    if (currentOutput > (now - _windowStartTime) * 255.0 / _windowSize)
    {
        digitalWrite(_outputPin, HIGH);
    }
    else
    {
        digitalWrite(_outputPin, LOW);
    }
}
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
